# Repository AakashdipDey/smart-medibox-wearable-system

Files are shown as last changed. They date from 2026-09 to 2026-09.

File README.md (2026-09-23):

# Smart Medication Dispensing & Telemetry System
### Integrated IoT Healthcare Ecosystem: MediBox Base-Station & Wearable Companion







An end-to-end smart healthcare hardware ecosystem engineered to tackle patient medication non-adherence and remote health monitoring. The system comprises two synchronized hardware platforms:

1. **MediBox Base-Station:** A high-current automated 7-compartment pill dispenser with precision weight sensing and mechanical dispensing.
2. **Wearable Companion:** An ultra-compact, low-power wrist-worn ESP32-S3 device providing patient haptic alerts, battery monitoring, and biometric sensor interfacing.

---

## System Architecture Overview

```
 ┌─────────────────────────────────────────────────────────────────────────────────┐
 │                               MEDIBOX BASE-STATION                              │
 │                                                                                 │
 │   ┌─────────────────┐       ┌────────────────────────┐      ┌───────────────┐   │
 │   │  7.4V Li-Po /   │  ───> │ LM2596 Buck Regulator  │ ───> │  5V Bus Rail  │   │
 │   │  USB-C Charger  │       │ (1000µF Bulk Filtering)│      │  (60mil Cu)   │   │
 │   └─────────────────┘       └────────────────────────┘      └───────┬───────┘   │
 │                                                                     │           │
 │       ┌─────────────────────────────────────────────────────────────┼───────┐   │
 │       │                                                             │       │   │
 │   ┌───▼────────────────┐   ┌───────────────────────────┐        ┌───▼───┐ ┌─▼─┐ │
 │   │ 7x SG90 Servos     │   │ ESP32 Core Controller     │        │WS2812B│ │BUZ│ │
 │   │ (PWM1 - PWM7)      │ <─┤ - Wi-Fi & BLE Gateway     │ ─────> │RGB LED│ │ZER│ │
 │   └────────────────────┘   │ - Shared SCK Bus (GPIO19) │        │Strip  │ │   │ │
 │   ┌────────────────────┐   │ - 7x Dedicated Data Lines │        └───────┘ └───┘ │
 │   │ 7x HX711 Load Cell │ ─>│   (DT1 - DT7)             │                        │
 │   │ Weight Amplifiers  │   └─────────────┬─────────────┘                        │
 │   └────────────────────┘                 │                                      │
 └──────────────────────────────────────────┼──────────────────────────────────────┘
                                            │ BLE 5.0 Wireless Telemetry
                                            ▼
 ┌─────────────────────────────────────────────────────────────────────────────────┐
 │                               WEARABLE COMPANION                                │
 │                                                                                 │
 │   ┌──────────────┐     ┌──────────────────────┐     ┌───────────────────────┐   │
 │   │ USB Type-C   │ ──> │ Microchip MCP73831   │ ──> │ 3.7V Li-Po Battery    │   │
 │   │ (5.1k CC)    │     │ Li-Ion Charger (SOT) │     │ (ADC State-of-Charge) │   │
 │   └──────┬───────┘     └──────────────────────┘     └───────────┬───────────┘   │
 │          │                                                      │               │
 │          └───────────┐                             ┌────────────┘               │
 │                      ▼                             ▼                            │
 │            ┌───────────────────────────────────────────────┐                    │
 │            │ Power Path Management (DMG2305 P-FET + Diode) │                    │
 │            └───────────────────────┬───────────────────────┘                    │
 │                                    ▼                                            │
 │                      ┌───────────────────────────┐                              │
 │                      │ AP2112K 3.3V 600mA LDO    │                              │
 │                      └─────────────┬─────────────┘                              │
 │                                    ▼                                            │
 │                      ┌───────────────────────────┐      ┌───────────────────┐   │
 │                      │ ESP32-S3-MINI-1-N8 SoC    │ ───> │ Haptic ERM Driver │   │
 │                      │ - 240MHz Xtensa Dual-Core │      │ (SI2302 + Flyback)│   │
 │                      │ - Built-in PCB Antenna    │      └───────────────────┘   │
 │                      │ - 4-Pin 0.5mm FPC Header  │ ───> Biometric / Display     │
 │                      └───────────────────────────┘                              │
 └─────────────────────────────────────────────────────────────────────────────────┘
```

---

## Subsystem 1: MediBox Base-Station

The **MediBox** serves as the central dispensing terminal, featuring 7 independently monitored medicine bays (one for each day of the week or multi-dose regimens).

### Hardware Design Highlights
* **Precision Pill Verification:** Each compartment integrates an **HX711 24-bit ADC / Load Cell Amplifier** module (`P1` - `P7`). 
  * Enables gravimetric sensing to verify that medication has physically dropped into the patient cup.
  * Employs a synchronized bus topology: all 7 load cells share a master clock (`SCK` on GPIO 19), with 7 discrete serial data return lines (`DT1` - `DT7` mapped to GPIOs 15, 2, 4, 16, 17, 5, 18).
* **Automated Dispensing Actuation:** Driven by 7 **SG90 micro servo motors** (`S1` - `S7`) controlled via dedicated hardware PWM outputs (`PWM1` - `PWM7` on GPIOs 13, 12, 14, 27, 26, 25, 33).
* **High-Current Power Distribution:** 
  * Accepts 7.4V 2S Li-Po battery or Type-C input.
  * Features an **LM2596 high-efficiency step-down switching regulator** capable of delivering up to 3A continuous at 5V.
  * Includes a **1000 µF low-ESR electrolytic capacitor (`C1`)** placed directly across the 5V power bus to suppress high-transient inrush currents when multiple servos actuate simultaneously.
  * Routed with **60 mil (1.52 mm) heavy-copper traces** to maintain tight voltage regulation and prevent MCU brownout.
* **Audio-Visual Patient Feedback:** 
  * Addressable WS2812B RGB LED strip header (`J8`) with a 330Ω inline series resistor (`R1`) for signal reflection damping.
  * Active buzzer connector (`J9`) driven by GPIO 22 for audible dose alarms.

### MediBox Schematic
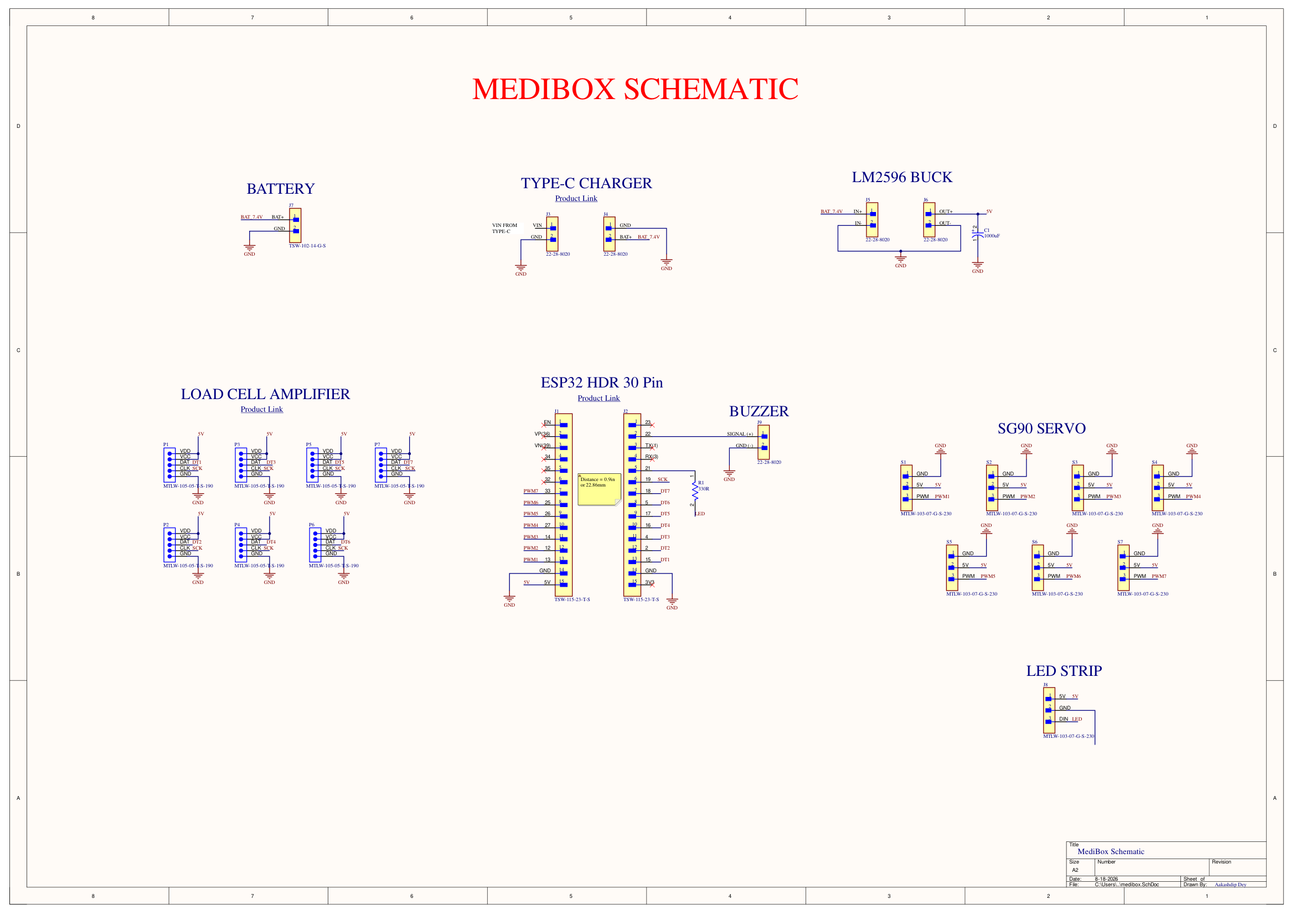
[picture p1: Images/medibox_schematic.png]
MediBox Schematic

*Figure 1: Complete MediBox schematic showing ESP32 pin breakout, HX711 cluster, servo bus, and LM2596 power stage.*

---

## Subsystem 2: Wearable Companion

The **Wearable Companion** is an ultra-compact, wrist-worn device designed to ensure patients never miss a medication window even when away from the base station.

### Hardware Design Highlights
* **Core Processing & RF:** **Espressif ESP32-S3-MINI-1-N8** with onboard PCB antenna, providing low-power BLE 5 advertising and mesh synchronization with the MediBox base station.
* **Intelligent Power Path Management:**
  * Uses a **Diodes Inc. DMG2305UX P-channel MOSFET** and an **onsemi MBR0520 Schottky barrier diode** to create an automatic ideal-diode power path switch.
  * Seamlessly powers the system from USB-C (5V) while simultaneously recharging the battery, without passing charging current through the cell.
* **Li-Ion Charge Management:**
  * **Microchip MCP73831T-2ACI/OT** standalone linear Li-Ion / Li-Polymer charger in SOT-23-5.
  * Pre-configured constant current / constant voltage charging algorithm with red LED charge status indicator (`D2`).
* **Ultra-Low Dropout Regulation:** **Diodes Inc. AP2112K-3.3TRG1** 600mA CMOS LDO delivering clean 3.3V with 250mV typical dropout voltage.
* **Haptic Vibration Actuation:**
  * Discrete driver circuit utilizing a **Vishay SI2302 N-channel MOSFET (`Q1`)** to drive an eccentric rotating mass (ERM) vibration motor (`M1`).
  * Clamped with a **Diodes Inc. B0540W Schottky freewheeling diode (`D1`)** to safely snub inductive flyback voltage spikes.
* **Peripheral FPC Expansion:** 
  * **Molex 503480-0440** 4-pin 0.5mm pitch right-angle FPC connector (`J1`) routing 3.3V, GND, and I2C/SPI lines for connecting an external PPG pulse oximeter sensor, IMU, or flexible OLED display.

---

## PCB Stackup & Manufacturing Specifications

### MediBox Base-Station PCB
* **Layer Count:** 2 Layers (Top Layer, Bottom Layer)
* **Trace Rules:** 8-10 mil signal traces; **60 mil heavy-current power traces** for 5V and 7.4V servo rails.
* **Thermal Relief:** 4-finger 10 mil conductor relief on ground polygons.
* **DRC Status:** **0 Violations**.

### Wearable Companion PCB
* **Layer Count:** 4 Layers (High-density compact stackup)
* **Trace Rules:** 7-10 mil signals; 25 mil preferred power traces (`VBUS_5V`, `3V3_RAIL`, `VBAT_RAW`, `SYS_VCC`).
* **Ground Distribution:** Solid continuous ground plane for RF antenna return and noise isolation.
* **DRC Status:** **0 Violations**.

---

## Bill of Materials (Key Components)

### MediBox Key Parts
| Designator | Component | Description | Function |
|:---|:---|:---|:---|
| **J1, J2** | Samtec TSW-115-23-T-S | 15-Pin Female Breakout Headers (2.54mm) | ESP32 Module Breakout Interface |
| **P1 - P7** | Samtec MTLW-105-05-T-S | 5-Pin Vertical Headers | 7x HX711 Load Cell Interface (VCC, DAT, CLK, GND) |
| **S1 - S7** | Samtec MTLW-103-07-G-S | 3-Pin Vertical Headers | 7x SG90 Micro Servo Connections (5V, GND, PWM) |
| **J5, J6** | Molex 22-28-8020 | 2-Pin Friction Lock Headers | LM2596 Buck Converter Input & Output |
| **C1** | 1000 µF / 16V | Electrolytic Radial Bulk Capacitor | High-inrush transient suppression for servos |
| **R1** | 330 Ω (0805) | Carbon Film Resistor | WS2812B Data line ringing dampener |
| **J8** | Samtec MTLW-103-07-G-S | 3-Pin Header | Addressable RGB LED Strip Interface |
| **J9** | Molex 22-28-8020 | 2-Pin Header | Active Piezo Buzzer Connection |

### Wearable Companion Key Parts
| Designator | Component | MPN | Package | Function |
|:---|:---|:---|:---|:---|
| **U1** | ESP32-S3 SoC Module | `ESP32-S3-MINI-1-N8` | SMD Module | Central processor, BLE 5 & Wi-Fi |
| **U2** | 600mA Low-Dropout LDO | `AP2112K-3.3TRG1` | SOT-25 | 3.3V System power regulation |
| **U3** | Li-Ion Charge Controller | `MCP73831T-2ACI/OT` | SOT-23-5 | 4.2V Single-cell Li-Po charger |
| **USB_J** | USB Type-C Receptacle | `217179-0001` | SMT Hybrid | 24-Pin USB-C port & charging input |
| **Q1** | N-Channel MOSFET 20V 2.8A | `SI2302CDS-T1-GE3` | SOT-23 | Haptic vibration motor driver |
| **Q2** | P-Channel MOSFET 20V 4.2A | `DMG2305UX-7` | SOT-23 | Automatic power-path switcher |
| **D1** | Schottky Barrier Diode 40V | `B0540W-7-F` | SOD-123 | Motor inductive flyback clamp |
| **D2** | Red SMD LED | 0603 Package | 0603 | Charging state indicator |
| **D3** | Schottky Barrier Diode 20V | `MBR0520LT1G` | SOD-123 | Power path ORing diode |
| **J1** | 4-Pin 0.5mm FPC Connector | `503480-0440` | SMT RA | Sensor / Display flex cable interface |
| **M1** | 2-Pin Solder Header | 2-Pin 2.54mm | Header | ERM coin vibration motor connection |
| **SW1, SW2** | SPST Tactile Switch | `PTS645SM43SMTR92LFS` | SMD Tact | Reset & Boot buttons |

---

## Repository Structure

```
├── MediBox-Base-Dispenser/
│   ├── Hardware/
│   │   ├── medibox.PrjPcb             # Altium project file
│   │   ├── medibox.SchDoc             # MediBox schematic
│   │   └── medibox.PcbDoc             # 2-layer high-current PCB layout
│   ├── Fabrication/
│   │   ├── medibox.GTL / .GBL         # Top & Bottom Copper Gerbers
│   │   ├── medibox.GTO / .GBO         # Silkscreen layers
│   │   ├── medibox.GTS / .GBS         # Soldermask layers
│   │   ├── medibox.TXT                # NC Drill data
│   │   └── Design_Rule_Check.drc      # DRC verification report (0 errors)
│   └── Documentation/
│       ├── medibox_schematic.pdf      # High-resolution vector schematic
│       └── medibox_schematic_preview.png
├── Wearable-Companion/
│   ├── Hardware/
│   │   ├── wearable.PrjPcb            # Altium project file
│   │   ├── wearable_sch.SchDoc        # Wearable schematic
│   │   ├── wearable2.PcbDoc           # 4-layer ultra-compact PCB layout
│   │   ├── wearable.SchLib            # Schematic component library
│   │   ├── wearable_pcb.PcbLib        # Footprint library
│   │   └── wearable.BomDoc            # Altium LiveBOM document
│   ├── Fabrication/
│   │   ├── wearable2.GTL / .GBL       # Top & Bottom Copper Gerbers
│   │   ├── wearable2.G1 / .GP1        # Internal Ground & Power planes
│   │   ├── wearable2.GTO / .GBO       # Silkscreen layers
│   │   ├── wearable2.GTS / .GBS       # Soldermask layers
│   │   ├── wearable2-RoundHoles.TXT   # NC Drill coordinates
│   │   └── Design_Rule_Check.drc      # DRC verification report (0 errors)
│   └── Documentation/
│       └── Wearable_Bill_of_Materials.pdf # Detailed component procurement BOM
├── Images/
│   └── medibox_schematic.png          # High-resolution schematic preview
└── README.md
```

---

## Author & Contact

**Aakashdip Dey**  
*Hardware & Embedded Electronics Engineer*  
* Vellore, India  
* GitHub: [@AakashdipDey](https://github.com/AakashdipDey)

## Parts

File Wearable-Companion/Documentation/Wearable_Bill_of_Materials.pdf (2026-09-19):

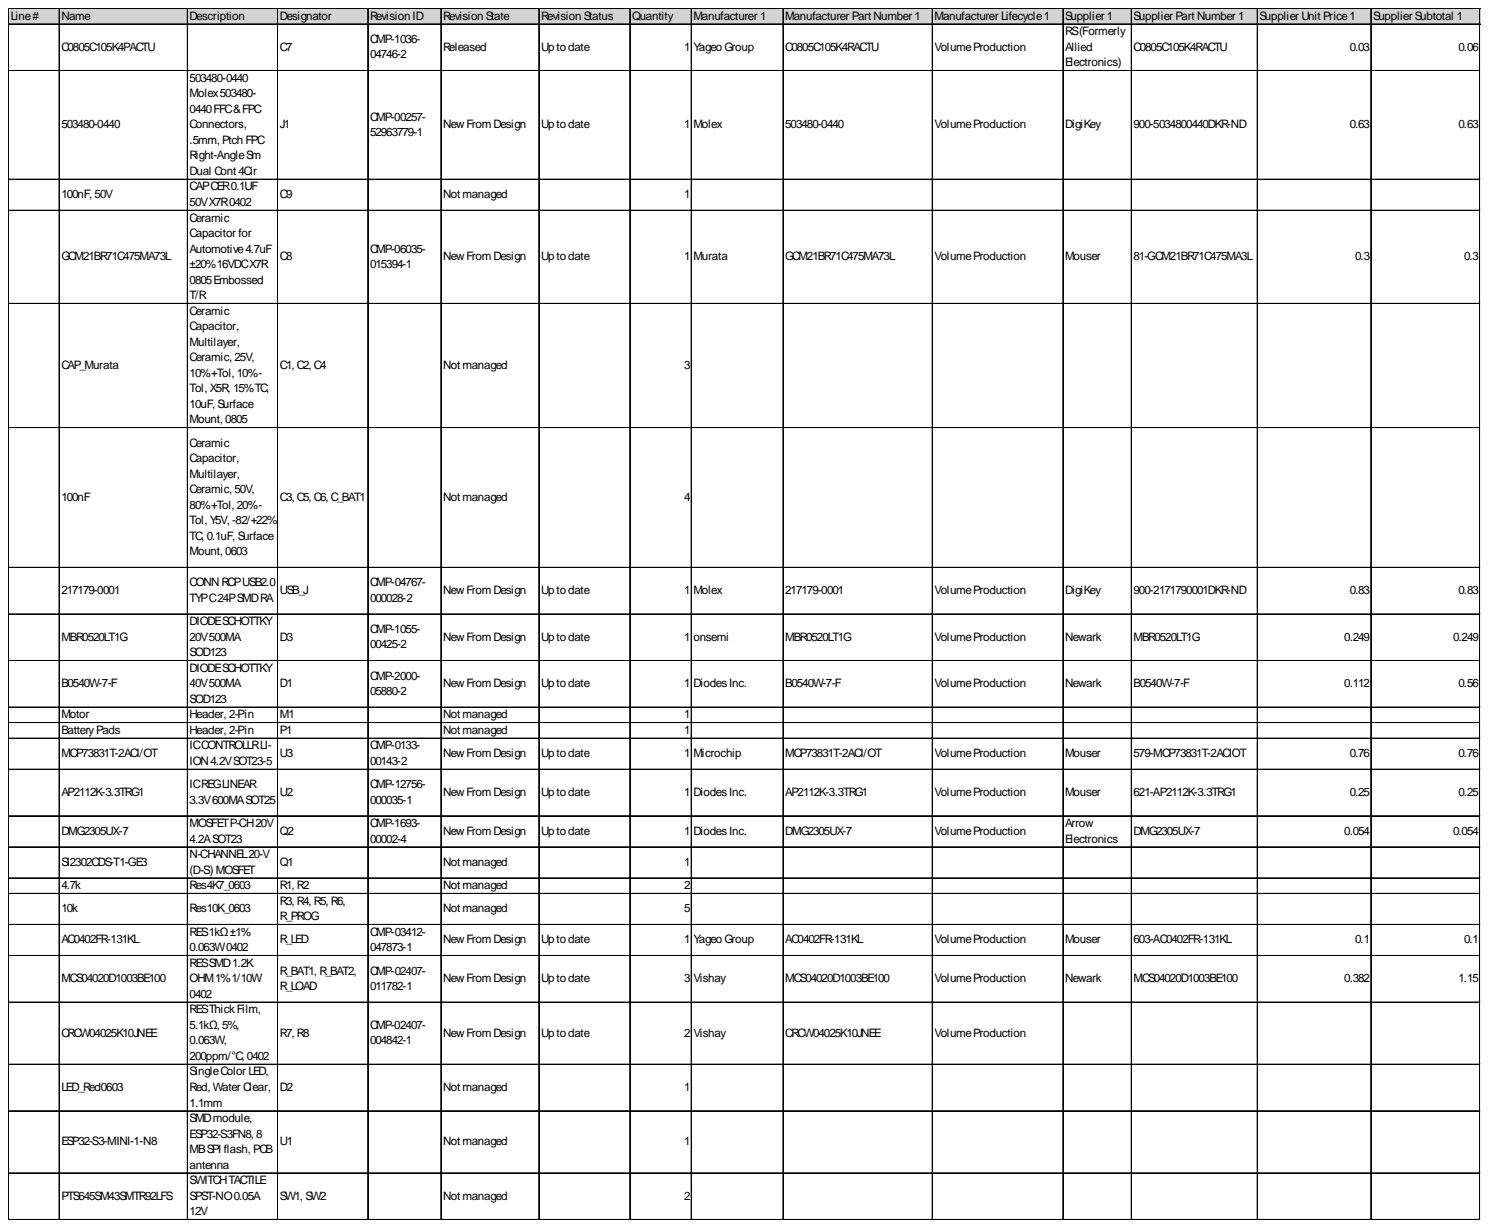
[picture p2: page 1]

Line# | Name | Description | Designator | Revision ID | Revision State | Revision Status | Quantity | Manufacturer 1 | Manufacturer Part Number 1 | Manufacturer Lifecycle1 | Supplier 1 | Supplier Part Number 1 | Supplier Unit Price1 | Supplier Subtotal 1

C0805C105K4PACTU | | C7 | CMP-1036-04746-2 | Released | Up to date | 1 Yageo Group | | C0805C105K4RACTU | VolumeProduction | RS(Formerly Allied Electronics) | C0805C105K4RACTU | 0.03 | 0.06

503480-0440 | 503480-0440 Molex503480-0440FFC&FPC Connectors, .5mm, Ptch FPC Right-AngleSm Dual Cont 4Cir | J1 | CMP-00257-52963779-1 | New From Design | Up to date | 1 Molex | | 503480-0440 | VolumeProduction | DigiKey | 900-5034800440DKR-ND | 0.63 | 0.63

100nF, 50V | CAPCER0.1UF 50VX7R0402 | C9 | | Not managed | | 1

GCM21BR71C475MA73L | Ceramic Capacitor for Automotive4.7uF ±20%16VDCX7R 0805Embossed T/R | C8 | CMP-06035-015394-1 | New From Design | Up to date | 1 Murata | | GCM21BR71C475MA73L | VolumeProduction | Mouser | 81-GCM21BR71C475MA3L | 0.3 | 0.3

CAP_Murata | Ceramic Capacitor, Multilayer, Ceramic, 25V, 10%+Tol, 10%-Tol, X5R, 15%TC, 10uF, Surface Mount, 0805 | C1, C2, C4 | | Not managed | | 3

100nF | Ceramic Capacitor, Multilayer, Ceramic, 50V, 80%+Tol, 20%-Tol, Y5V, -82/+22% TC, 0.1uF, Surface Mount, 0603 | C3, C5, C6, C_BAT1 | | Not managed | | 4

217179-0001 | CONN RCPUSB2.0 TYPC24PSMDRA | USB_J | CMP-04767-000028-2 | New From Design | Up to date | 1 Molex | | 217179-0001 | VolumeProduction | DigiKey | 900-2171790001DKR-ND | 0.83 | 0.83

MBR0520LT1G | DIODESCHOTTKY 20V500MA SOD123 | D3 | CMP-1055-00425-2 | New From Design | Up to date | 1 onsemi | | MBR0520LT1G | VolumeProduction | Newark | MBR0520LT1G | 0.249 | 0.249

B0540W-7-F | DIODESCHOTTKY 40V500MA SOD123 | D1 | CMP-2000-05880-2 | New From Design | Up to date | 1 Diodes Inc. | | B0540W-7-F | VolumeProduction | Newark | B0540W-7-F | 0.112 | 0.56

Motor | Header, 2-Pin | M1 | | Not managed | | 1
BatteryPads | Header, 2-Pin | P1 | | Not managed | | 1
MCP73831T-2ACI/OT | ICCONTROLLRLI-ION 4.2VSOT23-5 | U3 | CMP-0133-00143-2 | New From Design | Up to date | 1 Microchip | | MCP73831T-2ACI/OT | VolumeProduction | Mouser | 579-MCP73831T-2ACIOT | 0.76 | 0.76

AP2112K-3.3TRG1 | ICREGLINEAR 3.3V600MASOT25 | U2 | CMP-12756-000035-1 | New From Design | Up to date | 1 Diodes Inc. | | AP2112K-3.3TRG1 | VolumeProduction | Mouser | 621-AP2112K-3.3TRG1 | 0.25 | 0.25

DMG2305UX-7 | MOSFETP-CH20V 4.2ASOT23 | Q2 | CMP-1693-00002-4 | New From Design | Up to date | 1 Diodes Inc. | | DMG2305UX-7 | VolumeProduction | Arrow Electronics | DMG2305UX-7 | 0.054 | 0.054

SI2302CDS-T1-GE3 | N-CHANNEL20-V (D-S) MOSFET | Q1 | | Not managed | | 1

4.7k | Res4K7_0603 | R1, R2 | | Not managed | | 2
10k | Res10K_0603 | R3, R4, R5, R6, R_PROG | | Not managed | | 5

AC0402FR-131KL | RES1kΩ±1% 0.063W0402 | R_LED | CMP-03412-047873-1 | New From Design | Up to date | 1 Yageo Group | | AC0402FR-131KL | VolumeProduction | Mouser | 603-AC0402FR-131KL | 0.1 | 0.1

MCS04020D1003BE100 | RESSMD1.2K OHM1%1/10W 0402 | R_BAT1, R_BAT2, R_LOAD | CMP-02407-011782-1 | New From Design | Up to date | 3 Vishay | | MCS04020D1003BE100 | VolumeProduction | Newark | MCS04020D1003BE100 | 0.382 | 1.15

CRCW04025K10JNEE | RESThick Film, 5.1kΩ, 5%, 0.063W, 200ppm/°C, 0402 | R7, R8 | CMP-02407-004842-1 | New From Design | Up to date | 2 Vishay | | CRCW04025K10JNEE | VolumeProduction

LED_Red0603 | SingleColor LED, Red, Water Clear, 1.1mm | D2 | | Not managed | | 1

ESP32-S3-MINI-1-N8 | SMDmodule, ESP32-S3FN8, 8 MBSPI flash, PCB antenna | U1 | | Not managed | | 1

PTS645SM43SMTR92LFS | SWITCHTACTILE SPST-NO0.05A 12V | SW1, SW2 | | Not managed | | 2

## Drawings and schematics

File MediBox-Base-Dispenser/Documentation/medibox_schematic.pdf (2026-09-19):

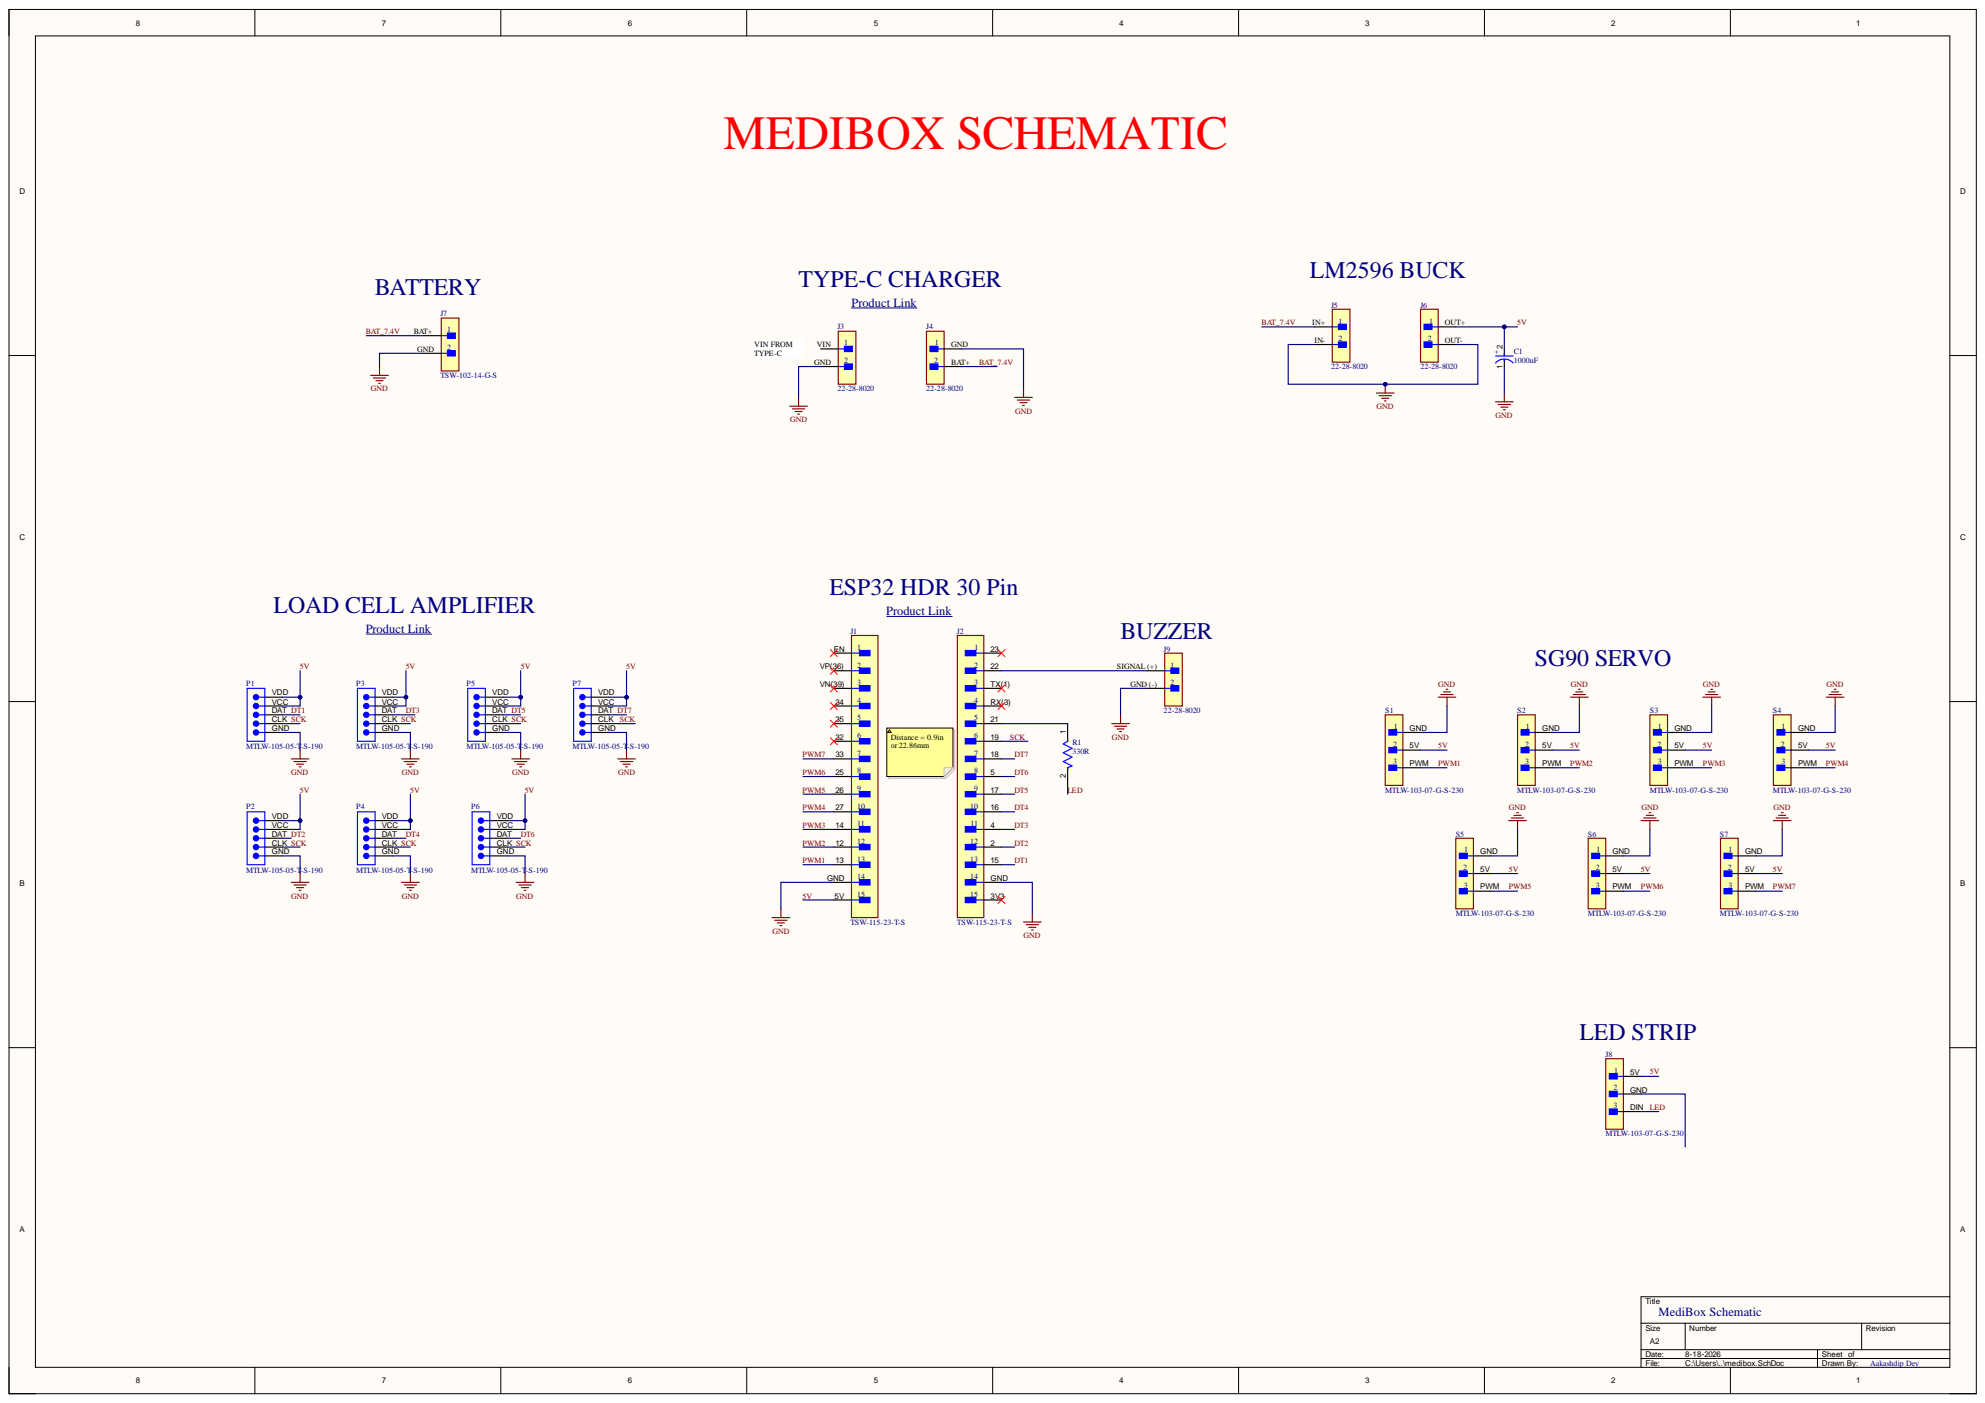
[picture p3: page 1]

TYPE-C CHARGER Product Link

LOAD CELL AMPLIFIER Product Link

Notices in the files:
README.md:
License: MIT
